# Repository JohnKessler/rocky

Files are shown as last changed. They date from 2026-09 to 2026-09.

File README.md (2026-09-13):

# Rocky



A compact desk companion. A round face that shows what it is thinking, a camera
that watches the room, a head on two motors that turns to look at you, and a
voice with opinions.

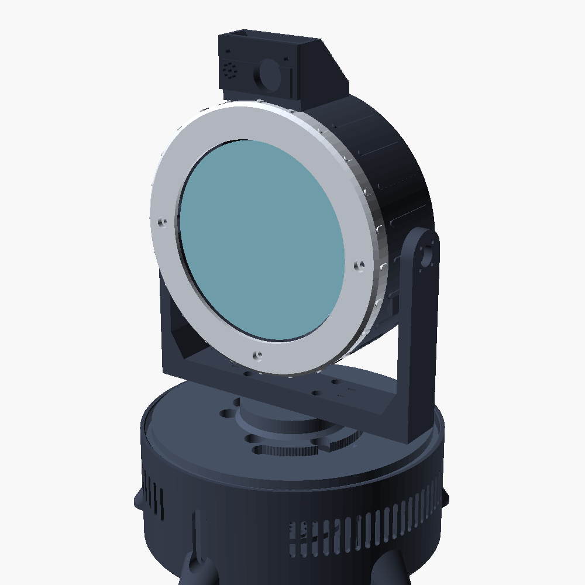
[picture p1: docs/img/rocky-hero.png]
Rocky


Rocky is an alien engineer who lives on your desk. It is blind in the way its
own kind are blind, it thinks in chords rather than words, and it finds most
things about humans genuinely puzzling. Ask it something and it will turn to
face you, think about it visibly, and answer in a sentence or two — usually
after a chord, because a chord is its first language and English is a
translation.

**188 × 184 × 273 mm — about 0.33 cubic feet.**

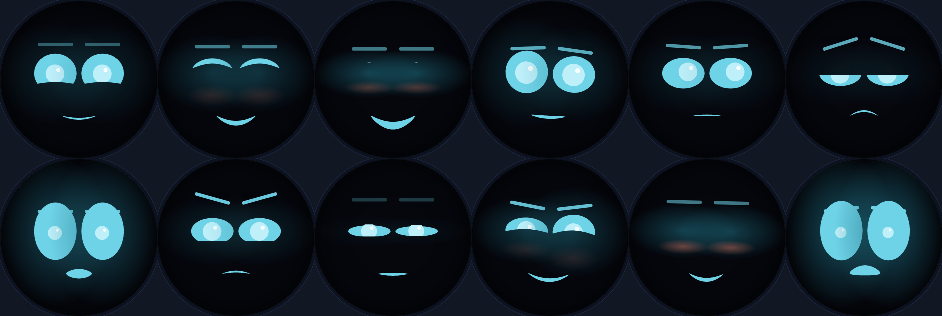
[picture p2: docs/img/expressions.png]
Rocky's expressions


---

## What it does

- **Watches.** A wide camera finds faces and the head turns to hold you near
  the centre of frame. When nobody is there it looks around now and then, the
  way something alive does.
- **Listens.** Wake word, then speech recognition. Or leave the mic open if
  you work alone.
- **Talks.** A voice pushed away from human, introduced by a musical motif
  chosen to match the expression.
- **Reacts.** Nineteen expressions and twelve gestures, driven by what Rocky
  actually means rather than sprinkled on afterwards. It nods while still
  looking at you.
- **Remembers.** Short facts it chose to keep, in a SQLite file you can open,
  read and delete.
- **Is tunable.** A dashboard for watching everything it does and adjusting
  how it behaves, live.

---

## Try it before you build it

Every hardware backend has a simulated twin, so the whole robot runs on a
laptop with nothing attached. The simulator is closed-loop: there is a subject
at a bearing in a synthetic room, turning the head moves it across the frame,
and face tracking genuinely converges.

```bash
git clone https://github.com/JohnKessler/rocky && cd rocky
python3 -m venv .venv && . .venv/bin/activate
pip install -e .

export ANTHROPIC_API_KEY=sk-ant-...     # optional; without it Rocky moves and
                                        # chirps but does not converse
rocky --sim run
```

Open **http://localhost:8080**. You get Rocky's real face — the browser renders
from the same parameter vector the display does — a simulated camera view with
detections, and every control the robot has.

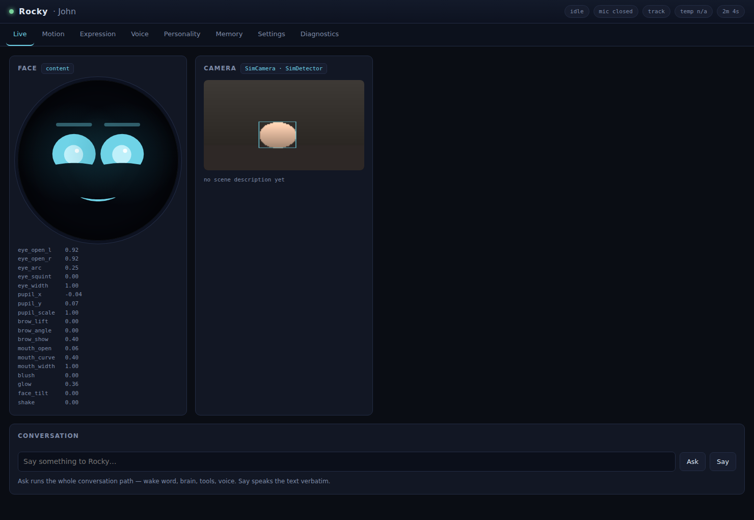
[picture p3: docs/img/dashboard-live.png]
Dashboard


Type into the conversation box. That text enters the pipeline at exactly the
point a real transcript would, so it exercises the whole path rather than a
shortcut around it.

---

## Building one

| | |
|---|---|
| **[Bill of materials](docs/BOM.md)** | Every part, what the specification actually needs to be, and what is worth spending money on. £330–£420. |
| **[Printing](docs/PRINTING.md)** | Eleven parts, ~780 g, two days of printer time. Settings and orientation per part. |
| **[Wiring](docs/WIRING.md)** | Pin by pin, plus the `config.txt` lines that make the Pi see the hardware. |
| **[Assembly](docs/ASSEMBLY.md)** | Four hours, in an order that works. |
| **[Software](docs/SOFTWARE.md)** | Install, calibrate, tune, and what every setting does. |
| **[Architecture](docs/ARCHITECTURE.md)** | How the code fits together, and why. |

Short version: Raspberry Pi 5 in the head behind a 4″ round display, Camera
Module 3 Wide in a sensor brow above the face, pan and tilt on a PCA9685,
I²S amplifier driving a down-firing speaker in the base, one 12 V input.

The CAD is parametric. Every dimension lives in one file, and the build script
re-renders all ten parts and checks each mesh is watertight, manifold and in
one piece before you waste filament on it.

```bash
cd hardware/cad && ./build_all.sh
```

---

## Repository

```
docs/            build guides and architecture notes
  bench-guide.html  the assembly, one stage at a time, for a phone at the bench
hardware/
  cad/           OpenSCAD source - rocky_params.scad holds every dimension
  stl/           exported, validated meshes
  wiring/        the wiring as data; generates the diagrams and the tables
  img/           assembly renders and wiring diagrams
  update_docs.py folds both into the guides
  README.md      how the graphics are generated
software/rocky/
  core/          event bus and service lifecycle
  face/          expressions, geometry, renderers
  motion/        kinematics, servos, gestures, tracking
  vision/        camera, detection, the simulated room
  audio/         wake word, speech, synthesis, chirps
  brain/         persona, memory, tools, conversation loop
  web/           dashboard API and front end
tests/           252 tests, all running against the simulated backends
scripts/         installer
systemd/         service unit
```

---

## How it is put together

Six services that never call each other. They publish events and subscribe to
topics, and one module knows they all exist. The consequences are worth the
indirection: a gesture the brain asked for and a gesture you triggered from the
dashboard take exactly the same path, and you can run Rocky without a camera by
editing one file.

Everything that touches hardware ships a real backend and a simulated one and
picks between them at runtime, which is why the test suite can boot the entire
robot.

Three decisions that shaped the rest:

- **The tilt axis runs through the head's centre of mass**, with a trim-weight
  post to get it there. Balanced, the tilt servo fights only inertia — which is
  what lets it be a micro servo, which is what lets the Pi fit beside it, which
  is what keeps the head small enough to balance.
- **The servos de-energise when the head has been still for a moment.** A
  digital servo holding position against its own gear lash hums continuously.
  This one setting is most of the difference between a robot you leave on your
  desk and one you put in a cupboard.
- **The camera lives in a brow above the face, not behind it.** A 24 mm camera
  board will not fit above a 110 mm display inside any sensible head diameter —
  the geometry simply does not close. So Rocky has an eye stalk, which suits it.

---

## A note on Rocky

The character is an affectionate original take in the manner of the Eridian
engineer from Andy Weir's *Project Hail Mary* — an alien who is blind,
tireless, completely without guile, and whose first language is music. The
persona prompt in `software/rocky/brain/persona.py` is written from scratch
rather than quoting the book, and the chords are synthesised rather than
sampled. It is a homage, built for one desk. If you build your own, keep it
that way.

---

## Licence

MIT for the code and the CAD. See [LICENSE](LICENSE).

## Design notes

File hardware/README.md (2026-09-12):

# Regenerating the graphics

Every picture in the guides is generated from the same source as the thing it
depicts, so a figure cannot quietly go stale. Nothing here is hand-drawn and
nothing needs to be redrawn when a dimension changes.

```
rocky_params.scad ──► part .scad ──► .stl ──────────┐
                                                     ├─► assembly_guide.scad ──► .png + .legend
                      components.scad ──────────────┘

wiring_data.py ──► generate.py ──► wiring-*.svg
               └─────────────────► tables.md

                                   update_docs.py ──► docs/ASSEMBLY.md, docs/WIRING.md
```

## The whole chain

```bash
cd hardware/cad && ./build_all.sh        # 11 parts, each mesh validated
./render_figures.sh                      # 9 figures + their legends
cd .. && python3 wiring/generate.py      # 3 diagrams + the tables
python3 update_docs.py                   # fold both into the markdown
```

`build_all.sh` and `render_figures.sh` need OpenSCAD on `PATH`. `generate.py`
and `update_docs.py` are plain Python with no dependencies.

## Assembly figures

`cad/assembly_guide.scad` imports the exported STLs and the stand-in components
in `cad/components.scad`, then draws one figure per assembly stage. Which
figures exist, and the camera for each, is the `FIGURES` list at the top of
`cad/render_figures.sh`:

```
"stage4|1800 1250|0,0,70,54,0,205,470|1.0|80"
 view   size       camera                explode  label distance
```

Callouts are numbered discs with leaders, not text in the model — text at model
scale is unreadable at some camera distances and illegible at others. Each
`callout()` echoes its own caption, `render_figures.sh` captures those into
`img/assembly-<view>.legend`, and `update_docs.py` writes them under the image
as a numbered key. The numbers in the picture and the words in the document
therefore come from one place and cannot disagree.

## Wiring diagrams

`wiring/wiring_data.py` is the single description of Rocky's electrics: the
devices, which half of the robot each lives in, every link between them, and
the conductors that cross the pan joint. `generate.py` renders it three ways
(power, GPIO header, interconnect) as hand-built SVG, and writes the same data
out as markdown tables.

`validate()` runs before anything is drawn and refuses to generate on a
contradiction. It checks that every link's endpoints exist, that no GPIO pin is
claimed twice, and — the rule that earns its keep — that any link joining a
device in the head to a device in the base is marked as crossing the pan joint.
That last check caught a real design error: the amplifier sat in the base while
the Pi sat in the head, which quietly put a 3 MHz I²S clock across a harness
that flexes every time Rocky turns. The amplifier moved into the head.

## Markers

`update_docs.py` fills the region between marker pairs in `docs/*.md`:

```markdown
<!-- figure:stage4 -->
<!-- /figure -->

<!-- wiring:power -->
<!-- /wiring -->

<!-- tables:harness -->
<!-- /tables -->
```

Anything between a pair is overwritten. Edit the source, re-run the chain, and
never edit inside the markers by hand.

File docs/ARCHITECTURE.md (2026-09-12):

# Architecture

How the code fits together, and the reasoning behind the parts that are not
obvious.

## The shape of it

Six services that never call each other. They publish events onto an in-process
bus and subscribe to topics; one module, `rocky/app.py`, knows they all exist.

```mermaid
graph LR
    subgraph inputs [ ]
        AUDIO[audio<br/>wake · speech · voice]
        VISION[vision<br/>camera · detection]
    end
    BUS{{event bus}}
    BRAIN[brain<br/>persona · memory · tools]
    subgraph outputs [ ]
        FACE[face<br/>expressions · animation]
        MOTION[motion<br/>servos · gestures · tracking]
    end
    WEB[web<br/>dashboard]

    AUDIO <--> BUS
    VISION --> BUS
    BUS <--> BRAIN
    BUS --> FACE
    BUS --> MOTION
    BUS <--> WEB
    MOTION -. pose .-> VISION
```

The indirection earns its keep three ways:

- A gesture the brain asked for and a gesture you clicked in the dashboard take
  **exactly the same path**, so the dashboard is a real test of the robot rather
  than a parallel implementation of it.
- Running without a camera, or with the face on another machine, is an edit to
  one file.
- Every service can be tested by feeding it events.

The dotted line from motion back to vision is the simulator closing its own
loop; on real hardware the world does that.

## Simulation is not a stub

Every hardware-facing module ships a real backend and a simulated one and picks
at runtime:

| | Real | Simulated |
|---|---|---|
| Servos | PCA9685 over I²C | records channel state |
| Camera | picamera2 | renders a room with someone in it |
| Detection | MediaPipe / Haar cascade | reads the simulator's ground truth |
| Display | pygame on the panel | records the parameter vector |
| Audio | PortAudio | room tone in, buffer out, **in real time** |
| Speech in | faster-whisper | a queue you can push text onto |
| Speech out | Piper / espeak-ng | silence of the right duration |

Two of these are worth dwelling on, because the easy version of each would have
made the simulator lie.

**The camera is closed-loop.** The subject sits at a real bearing in a synthetic
room and drifts slowly; where it lands in frame depends on where the head is
pointing, fed back from the motion service. Turn the head and the subject moves
across the frame as it would through a real lens. Face tracking therefore
genuinely converges in simulation, and a change that makes Rocky overshoot or
hunt shows up in a test instead of on your desk. If the subject falls outside
the lens's field of view it is simply not in the picture, which is what makes
the idle scanning behaviour mean anything.

**Simulated playback occupies real time.** Returning instantly would be faster,
but everything downstream of "Rocky is speaking" keys off how long it lasts —
the mouth animation, the gesture timing, and the gate that stops Rocky
transcribing its own voice. None of it would ever be exercised. The suite turns
this off via `hardware.sim_realtime_audio`; the one test that is actually about
speaking timing turns it back on for itself.

## The face is a parameter vector

An expression is a point in an eighteen-dimensional space and everything between
two expressions is a blend, so the face travels rather than cutting. Three
layers stack each frame:

1. the expression, cross-fading toward whatever was last requested
2. involuntary life — blinks, saccades, a slow swell in the glow
3. gaze, so the pupils reach you before the head finishes turning

Layer 2 is what stops the face reading as a picture. A face that holds perfectly
still is unsettling in a way that is hard to name and impossible to miss.

Two renderers consume the same vector: pygame on the panel, and SVG in the
browser. Because both read the same numbers, the dashboard shows Rocky's actual
face. The geometry maths is duplicated — `layout()` in `face/renderer.py` and
`layout()` in `static/js/face.js` — which is a real cost, paid to keep the
websocket carrying eighteen floats instead of a video stream.

Rendering the dashboard in a browser found two bugs in geometry both renderers
shared: the eyelid mask covered the whole lower half of the eye regardless of
the arc parameter, erasing the pupils of every smiling face; and the mouth's
curve sign was inverted, so every smile drew as a frown.

## Motion has exactly one writer

Everything that wants to move the head publishes an event; the motion loop is
the only thing that writes to a servo. That single-writer rule is what stops
tracking, gestures and dashboard jogging fighting each other.

Each tick the commanded angle is:

```
base (tracking, or a look_at, or idle drift)  +  gesture overlay
```

Offsets, not absolute positions, which is why Rocky can nod while still looking
at you.

### The motion profile

`MotionProfile` computes the fastest speed from which it could still brake to a
standstill exactly on target, and never exceeds it. The result is a trapezoid —
ramp up, cruise, ramp down — which is the movement people read as deliberate
rather than servo-ish.

It uses the **discrete-time** braking solution, not `v = sqrt(2·a·d)`. The
continuous form permits a speed that overshoots by up to one integration step,
and overshoot on a head this size reads as a twitch. Solving
`v² + 2·a·dt·v − 2·a·d ≤ 0` accounts for the step. The tests assert zero
overshoot and bounded acceleration *of the commanded position*, which is the
physical claim — the servo is driven by position, not by the profile's internal
velocity variable.

### Tracking

Proportional, with a deadband, and deliberately not a full PID. An integral term
on a servo with backlash walks the head slowly off target; a derivative term on
a jittery detector makes it twitch. Proportional plus a deadband plus the
profile's own acceleration limit produces the unhurried turn that reads as
attention rather than machinery.

### Torque

The servos de-energise after `motion.idle_torque_off_s` at rest. A digital servo
holding position against its own gear lash hums continuously, and this one
setting is most of the difference between a robot you leave out and one you put
away.

## The brain

One manual tool-use loop, not the SDK's tool runner, because each tool call has
to become a bus event the instant it happens — Rocky's face should change while
it is still deciding what to say, and the runner does not expose that seam.

Ten tools, all of which act by publishing events. One is different: `see`
returns the actual camera frame as image content blocks rather than a
description, so the model looks at the picture.

The system prompt and the tool list are byte-identical every turn and are
cached. Situational context — what Rocky can see, what it remembers — goes into
the *user* turn rather than the system prompt, specifically so the cached prefix
survives. A clock in the system prompt would throw the cache away on every
single request.

Everything that costs an API call lives in `brain/`. Vision publishes frames and
detections and says when the room changed; it never calls the model. One place
spends money, one place to look when the bill is wrong.

## Memory

A table of short facts Rocky chose to keep and a rolling transcript, in a SQLite
file you can open with any tool. That is deliberate for something that lives on
your desk and remembers things about you: you should be able to see exactly what
it has and delete any of it, from the dashboard or with `sqlite3`.

Pruning is by uses then age, so something Rocky keeps coming back to survives
even when it is old.

## Configuration

One pydantic tree, live-patchable by dotted path, with bounds on every field.
The dashboard's settings tab is generated from the schema — type, bounds,
choices and help text — so adding a setting in Python gives it the right control
in the browser with the right limits and no edit to the front end.

The bounds are enforced wherever a value enters, which is why a slider cannot
drive a servo past its limits. Behind that, `motion/kinematics.py` clamps
whatever the config says to the envelope the printed parts allow, and behind
*that* the printed stop post and stop pins are physical.

## Where the CAD and the code meet

`hardware/cad/rocky_params.scad` and `software/rocky/` are kept in step by hand
at exactly three points, all of them documented in both places:

- `MECHANICAL_LIMITS` in `motion/kinematics.py` mirrors `pan_range` and
  `tilt_range`
- `vision.h_fov_deg` / `v_fov_deg` must match the fitted lens
- `face.width` / `face.height` must match the panel

Everything else about the chassis is invisible to the software.

## Reading order

If you are picking this up cold:

1. `core/events.py` — the vocabulary everything speaks
2. `core/bus.py` — how it moves
3. `motion/kinematics.py` — pure arithmetic, no hardware, fully tested
4. `face/expressions.py` — the face as numbers
5. `app.py` — the wiring, in one screen
6. `brain/agent.py` — the conversation loop

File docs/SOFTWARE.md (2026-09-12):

# Software

Install, calibrate, and tune.

## Install on the Pi

```bash
git clone https://github.com/JohnKessler/rocky /tmp/rocky
sudo /tmp/rocky/scripts/install.sh
```

That installs system packages, enables I²C, creates a `rocky` user with the
right groups, builds a virtualenv at `/opt/rocky/.venv`, and installs a systemd
unit. It is safe to re-run — it upgrades in place and leaves `config.toml`
alone.

Then put your API key where the service can find it:

```bash
sudo nano /etc/rocky/rocky.env     # ANTHROPIC_API_KEY=sk-ant-...
sudo systemctl start rocky
journalctl -u rocky -f
```

Without a key Rocky still watches, tracks, moves and chirps. It just does not
converse.

### Speech engines

The installer tries to install `faster-whisper`, `piper` and `openwakeword`.
They are large and occasionally fight a particular Pi image, so failure is
non-fatal: Rocky falls back to `espeak-ng` for speech out and to a
speech-triggered wake for speech in, and says so in the log.

Piper needs a voice model on disk. Download one and drop it in
`/opt/rocky/var/voices/`:

```bash
cd /opt/rocky/var/voices
wget https://huggingface.co/rhasspy/piper-voices/resolve/main/en/en_GB/alan/medium/en_GB-alan-medium.onnx
wget https://huggingface.co/rhasspy/piper-voices/resolve/main/en/en_GB/alan/medium/en_GB-alan-medium.onnx.json
```

Then set `audio.tts.voice = "en_GB-alan-medium"`.

For the wake word, openWakeWord ships several pretrained models but not
"hey rocky". Either train one (their docs cover it), pick an existing model and
set `audio.wake.model`, or set `audio.wake.backend = "energy"` and let any
sustained speech wake Rocky. Energy wake is pleasant if you work alone and
useless in a room with a television.

## Commands

```bash
rocky run                  # the normal one
rocky run --no-web         # without the dashboard
rocky --sim run            # everything simulated, works anywhere
rocky check                # probe the hardware and report what is real
rocky calibrate pan        # interactive centring, writes the trim back
rocky calibrate tilt
rocky ask "what can you see"
rocky say "Good, good, good."
rocky config               # print the effective configuration
```

`rocky check` is the one to run first on a fresh build. It reports every backend
as `ok` (real hardware) or `sim` (fell back), which turns "why is nothing
happening" into a list.

## Configuration

Precedence, lowest to highest:

```
defaults in config.py  →  config.toml  →  ROCKY_* environment  →  dashboard edits
```

Dashboard edits apply immediately and are lost on restart unless you press
**Save**, which writes them back to `config.toml`. That is deliberate: you can
experiment freely and a bad idea disappears when you restart.

Environment overrides use a double underscore between levels:

```bash
ROCKY_MOTION__PAN__MAX_SPEED_DPS=90
ROCKY_BRAIN__EFFORT=medium
ROCKY_LOG_LEVEL=DEBUG
```

Every setting is bounded, and the bounds are enforced wherever the value enters
— including from the dashboard, which is why a slider cannot drive a servo past
its limits.

## Calibration

### Servo centres

```bash
rocky calibrate pan
```

`a`/`d` nudge by a degree, `A`/`D` by five, `0` commands zero, `s` saves and
quits. It writes `motion.<axis>.centre_trim_deg`.

Do this rather than trying to get the horn splines mechanically perfect. A
standard servo spline is 1.5° per tooth, so mechanical alignment can only ever
get you within three quarters of a degree; the trim gets you exact.

### Camera field of view

`vision.h_fov_deg` and `v_fov_deg` must match your lens. They are what convert
"the face is 30% right of centre" into "turn 15 degrees", so a wrong value makes
Rocky consistently under- or over-shoot when it turns to look at you.

- Camera Module 3 **Wide**: 102 × 67 (the default)
- Camera Module 3 standard: 66 × 41

To check empirically: put your face at the edge of frame, let Rocky track it,
and watch whether the head lands short or long. Short means the FOV is set too
narrow.

### Tracking

If Rocky overshoots and corrects back, lower `motion.tracking.gain` — try 0.4.
If it creeps continuously while you sit still, raise
`motion.tracking.deadband`. If it feels twitchy, raise `damping`.

The **Motion** tab shows the head's position and its target on one map, which
makes overshoot and hunting obvious.

## Tuning Rocky's personality

The **Personality** tab has seven dials. They are not decoration — each one is
quoted into the prompt and read by the face and motion services, so a change
takes effect within a second or two.

| Dial | What it changes |
|---|---|
| `curiosity` | How often Rocky asks about things, and how much it looks around when idle |
| `chattiness` | Whether Rocky speaks unprompted, including whether it greets you |
| `playfulness` | Teasing, jokes, sillier chords |
| `warmth` | How openly it says it likes you |
| `formality` | Sentence register. Low is the default; Rocky's speech is plain by design |
| `energy` | Gesture amplitude, blink rate, speech pace |
| `focus` | How long it stays on a subject, and how much its eyes wander |

Rocky can turn these itself. Say "be quieter" and it will reach for its
`adjust_self` tool, which is the same code path as the slider.

To change the character more deeply, edit `software/rocky/brain/persona.py`.
It is assembled rather than written flat so you can read exactly what each dial
contributed.

## Cost

Rocky makes one API request per conversational turn, plus one small request
whenever it describes the scene.

Levers, in the order worth reaching for:

1. `vision.scene_interval_s` — how often Rocky looks at the room. The default
   of 45 s with `scene_on_change_only` is already conservative; raise it or set
   `brain.scene_in_context = false` to stop entirely.
2. `brain.effort` — `low` by default, because a spoken companion answers in a
   sentence or two and the gap between you stopping and Rocky starting matters
   more than depth. Raise it if you start asking harder questions.
3. `brain.history_turns` — how much conversation is resent each turn.
4. `brain.max_tokens` — a hard ceiling on the reply.

The system prompt and tool list are identical every turn and are cached, so most
of the per-turn input cost disappears after the first request. The **Personality**
tab shows requests, tokens and cache hits; if `cached` stays at zero across
several turns, something is varying in the prefix.

## Running it your own way

`rocky run` starts everything. If you want a subset, `RockyApp` takes a config
and starts whichever services you leave enabled:

```python
from rocky.app import RockyApp
from rocky.config import Config

cfg = Config.load()
cfg.vision.enabled = False      # no camera
cfg.motion.enabled = False      # no servos

app = RockyApp(cfg)
await app.start()
await app.say("Good, good, good.")
```

The web app can own the robot's lifecycle if you would rather embed it:

```python
from rocky.web.app import create_app
api = create_app(RockyApp(cfg), manage_lifecycle=True)
```

## Tests

```bash
pip install -e ".[dev]"
pytest
```

252 tests, about forty seconds, all against the simulated backends — so they
pass on a laptop, in CI, and on the robot. They are worth reading if you plan to
change anything: several assert on behaviour that is easy to break silently,
like the motion profile never overshooting, the eyelid never covering the pupil,
and the microphone being shut while Rocky talks.

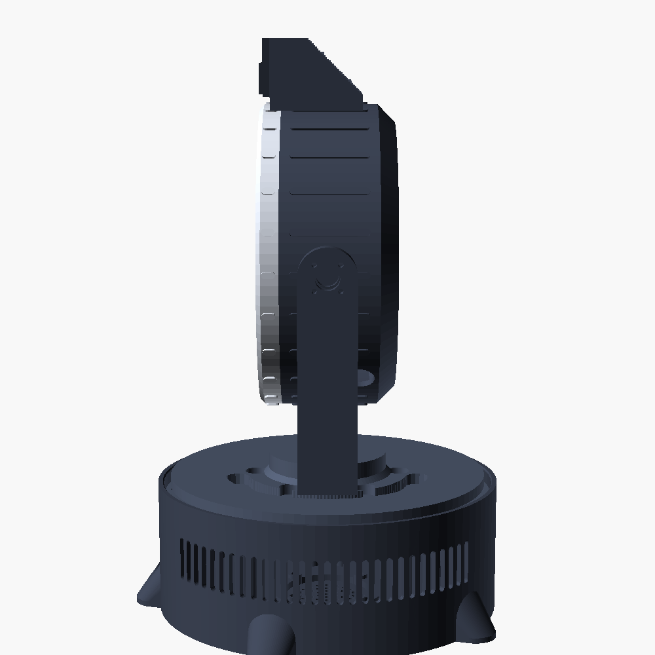
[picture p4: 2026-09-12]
hardware/img/rocky_side.png

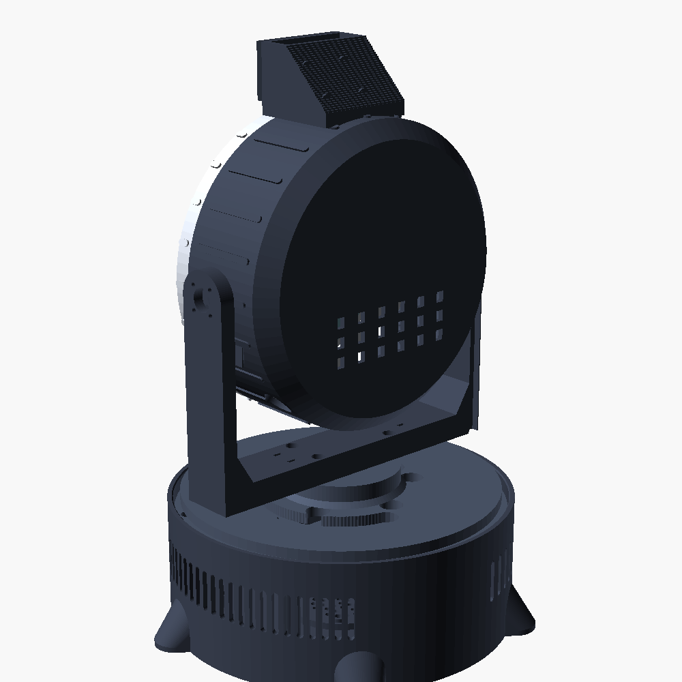
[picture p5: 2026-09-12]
hardware/img/rocky_three_quarter.png

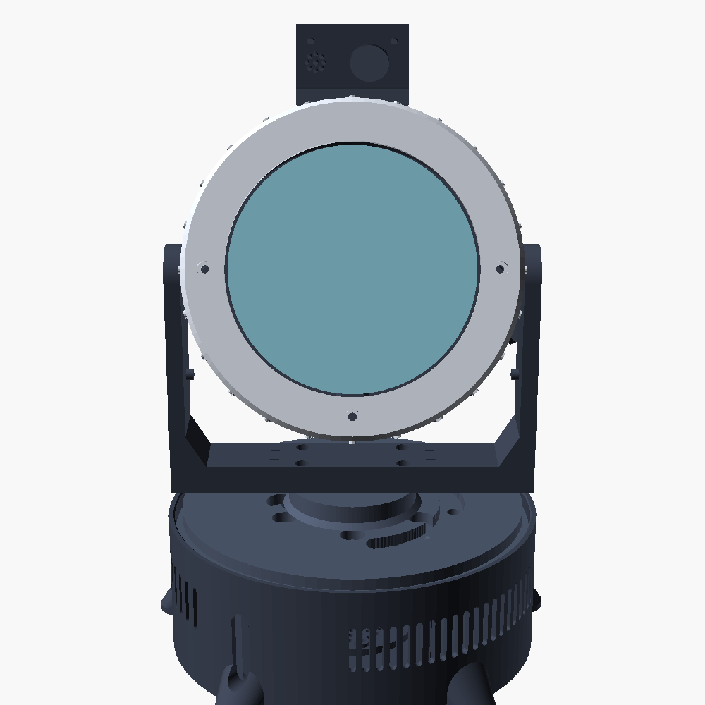
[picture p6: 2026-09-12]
hardware/img/rocky_tilted.png

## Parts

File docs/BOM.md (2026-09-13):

# Bill of materials

Everything needed to build one Rocky. Roughly **£330–£420 / $420–$530**
depending on which display and speech engine you choose and what you already
have in a drawer.

> **Check part numbers before you order.** SKUs and prices move, and vendors
> revise boards without renaming them. The **Specification** column is the part
> that actually matters — anything meeting it will work, and the code and the
> printed parts are parameterised so substitutions are a number change rather
> than a redesign. Where a dimension feeds the CAD, the parameter name is given
> so you know what to edit.
>
> Vendor SKUs were last checked on **12 September 2026**. Three were wrong at
> that point and are corrected below: the Qwiic cable had been retired, the
> speaker had been relabelled and had lost its colour-coded leads, and the
> microphone that was suggested does not fit the printed mount. The brow has
> since been recut around the flat stick instead (item 5.3), so the mount is
> now the part that changed rather than the microphone.

Vendor shorthand: **SF** SparkFun · **AF** Adafruit · **RPi** Raspberry Pi (or
any approved reseller) · **WS** Waveshare · **\*** generic, buy anywhere.

---

## 1. Brain

| # | Part | Specification | Where | ~Cost |
|---|---|---|---|---|
| 1.1 | Raspberry Pi 5, 8 GB | 8 GB matters: the face renderer, the detector and local speech all want headroom. 4 GB works if you use cloud speech. | RPi | £75 |
| 1.2 | Active Cooler for Pi 5 | The official one. Rocky's head is a closed box and the Pi will throttle without it. Its height sets `pi_stack_h`. | RPi | £5 |
| 1.3 | microSD card, 64 GB, A2 | A2 rating, not just "class 10". Cheap cards make boot and model loading miserable. | \* | £10 |
| 1.4 | *(optional)* NVMe HAT + 256 GB SSD | Only if you want local Whisper models to load quickly. Adds height in the head — check clearance first. | RPi | £45 |

## 2. Face

| # | Part | Specification | Where | ~Cost |
|---|---|---|---|---|
| 2.1 | **Option A —** 4″ round DSI display, 720×720 | Round IPS, MIPI-DSI, 60 Hz. This is the one the faceplate is drawn for. Measure the glass diameter and the carrier PCB and set `disp_glass_d`, `disp_pcb_w`, `disp_hole_dx/dy` before printing. | WS | £45 |
| 2.2 | **Option B —** Raspberry Pi Touch Display 2 | 5″, 720×1280, officially supported so the driver situation is boring. Not round: reprint `faceplate.scad` with `circular_mask=false` and a rectangular window, or accept a letterboxed face. Pick this if Option A's overlay fights your kernel. | RPi | £55 |
| 2.3 | DSI FPC cable, 22-pin 0.5 mm → 15-pin 1 mm, 200 mm | **Pi 5 only.** The Pi 5's connectors are the smaller 22-pin format; a standard 15-pin ribbon will not fit. Must be the *display* cable — the camera one is not interchangeable. | AF 5821 / WS | £5 |

## 3. Eyes

| # | Part | Specification | Where | ~Cost |
|---|---|---|---|---|
| 3.1 | Raspberry Pi Camera Module 3 **Wide** | 12 MP IMX708, autofocus, 102° × 67° FOV. Vendors advertise this lens as **120°**, which is the *diagonal* figure; 102° × 67° is the same lens measured horizontally and vertically, and horizontal is what the tracking maths wants. The wide version is the right call: the standard lens's 66° is too narrow to find you when Rocky is looking somewhere else. FOV feeds `vision.h_fov_deg` / `v_fov_deg` — get these wrong and Rocky consistently mis-aims when it turns to look at you. | RPi / AF 5658 | £30 |
| 3.2 | Camera FPC cable, 22-pin → 15-pin, 200 mm | Again Pi 5 specific, and again *not* the display cable. | AF 5818 / WS | £5 |

## 4. Motion

| # | Part | Specification | Where | ~Cost |
|---|---|---|---|---|
| 4.1 | Pan servo — standard size, metal gear, digital | 40.6 × 20 × 37 mm, ≥ 5 kg·cm at 6 V, 180°. A quiet digital servo is worth the extra: this one sits 30 cm from your ear. Hitec HS-5485HB or Savöx SH-0255MG are pleasant; MG996R works and is noticeably louder. Dimensions feed `sv_*`. | SF / \* | £18 |
| 4.2 | Tilt servo — micro, metal gear | 23 × 12.2 × 22.5 mm, ≥ 2 kg·cm. MG90S or Hitec HS-5065MG. **A standard servo will not fit** beside the Pi in the head — the head is sized around a micro here. Dimensions feed `msv_*`. | SF / \* | £8 |
| 4.3 | PCA9685 16-channel PWM/servo driver | I²C, 12-bit, external servo supply via screw terminal. Only two channels are used; the rest are there when you want to add something. | AF 815 / SF | £12 |
| 4.4 | Qwiic SHIM for Raspberry Pi | Slips over the GPIO header and gives you I²C on a connector **without covering the header**, which is what leaves GPIO 18/19/21 free for the amplifier. | SF DEV-15794 | £2 |
| 4.5 | Qwiic cable, 4-pin → female jumpers | Connects the SHIM to the PCA9685's I²C header. Wires are red/black/blue/yellow, matching the table in [WIRING.md](WIRING.md). **CAB-14988 (150 mm) is retired** — the current equivalent is the *Flexible Qwiic Cable – Female Jumper (4-pin)*, CAB-17261. Check the length suits; anything from 100–200 mm is fine. | SF CAB-17261 | £2 |
| 4.6 | Chrome steel balls, 6 mm × 30 | The slew ring. Buy 30 for 24 positions — you will lose some. 6 mm airsoft BBs work but wear faster and are noisier. | \* | £4 |
| 4.7 | 623ZZ bearing (3 × 10 × 4 mm) | The tilt idler pivot. | \* | £1 |
| 4.8 | 470 µF 10 V electrolytic capacitor | Across the servo rail at the PCA9685. Not optional — servo inrush browns out the I²C bus without it, and the symptom is Rocky freezing mid-move for no visible reason. | \* | £1 |

## 5. Voice

| # | Part | Specification | Where | ~Cost |
|---|---|---|---|---|
| 5.1 | MAX98357A I²S class-D amplifier | 3 W into 4 Ω, I²S in. The Pi 5 has no headphone jack, so this is required rather than optional. Mounts in the **head**, beside the Pi — that way the pan joint carries two analogue speaker conductors instead of five digital ones. | AF 3006 / SF | £6 |
| 5.2 | Speaker, 40 mm, 4 Ω, 3–5 W | Mounts in the **base** floor, firing down into the gap the legs hold open. Frame diameter feeds `spk_d`; the body is about 20 mm deep. Adafruit now lists 3968 as **5 W** where distributors still print 3 W — same part, and the extra headroom is harmless since the amplifier only delivers 3.2 W. The January 2024 revision has a concave cone and **no longer ships red/black leads**, so identify polarity yourself rather than by colour. | AF 3968 / \* | £4 |
| 5.3 | USB microphone, **flat stick, 22.2 × 18.3 × 7.0 mm** | The brow is cut for this exact shape: Adafruit's Mini USB Microphone (3367), and the physically identical part sold by Pi Hut, SunFounder, Cytron, Seeed and PiShop. It needs no bracket and no screws — stood on edge it drops into a slot moulded into the brow. Dimensions feed `mic_body_x/y/z`. **A cylindrical gooseneck or barrel mic will not fit**: the slot beside the camera is 13.6 mm wide and a 14 mm body overhangs the brow's wall. Anything else means editing `mic_body_*` and reprinting `head_back`, so measure before you buy. A small far-field array (ReSpeaker USB Mic Array, or similar) is a large improvement over a single capsule if Rocky sits more than a metre away, and is a separate mounting problem again. | \* | £8–£55 |
| 5.4 | USB-A right-angle adapter or short extension | The Pi's ports face sideways inside the head; a straight plug fouls the shell. | \* | £3 |

## 6. Power

Rocky takes **one 12 V input** and makes its own rails. Two wall warts on a desk
is an unforced ugliness, and feeding the Pi 5 from a bare 5 V supply makes it
throttle USB current and complain.

| # | Part | Specification | Where | ~Cost |
|---|---|---|---|---|
| 6.1 | 12 V 5 A PSU, 2.1 mm centre-positive barrel | 60 W. 3 A is enough in practice; 5 A means the servos never sag the rail. | \* | £12 |
| 6.2 | Step-down regulator, 5.1 V ≥ 5 A | For the Pi. Pololu D36V50F5 or equivalent. **5.1 V, not 5.0** — cable drop at 4 A is real and the Pi 5 is fussy about it. Hole spacing feeds `buck_hole_dx`. | Pololu / \* | £18 |
| 6.3 | Step-down regulator, 6 V ≥ 3 A | For the servo rail. 6 V gets meaningfully more torque and speed than 5 V out of the same servos. | Pololu / \* | £10 |
| 6.4 | USB-C breakout or a sacrificial USB-C cable | To feed the Pi's USB-C input from the 5.1 V rail. A cut-down cable is fine; solder to the 5 V and GND pairs. | \* | £4 |
| 6.5 | Panel-mount 2.1 mm DC jack | Base wall, cutout is `barrel_d`. | \* | £2 |
| 6.6 | 12 mm panel-mount latching switch | Base wall, cutout is `switch_d`. | \* | £3 |
| 6.7 | Inline fuse holder + 3 A fuse | On the 12 V input. A shorted servo lead behind a 5 A supply is a fire, not a fault. | \* | £2 |

## 7. Fasteners

Buy an M2/M2.5/M3 assortment and a heat-set insert kit; it is cheaper than
buying each length and you will use the rest.

| # | Part | Quantity | Notes |
|---|---|---|---|
| 7.1 | M3 heat-set inserts, 5.0 mm OD × 4.0 mm | 20 | Stage 1 uses 15. Pilot bores are `m3_insert_d`. |
| 7.2 | M2.5 heat-set inserts, 3.5 mm OD × 4.0 mm | 30 | Display, Pi, pan servo, and the pads in the base. Stage 1 uses 24; the rest are for the one you melt in crooked. Not the brow window — that takes self-tappers. |
| 7.3 | M2 heat-set inserts, 4.0 mm long | 10 | Camera posts and the amplifier pads, 6 in Stage 1. The bores in the CAD are `m2_insert_d` = 3.2 mm, so buy inserts specified for a 3.2 mm melt-in hole rather than by their OD. |
| 7.4 | M3 socket cap screws, 8 / 12 / 16 / 20 mm | 10 each | |
| 7.5 | M2.5 screws, 6 / 10 / 16 mm | 10 each | |
| 7.6 | M2 and M2.5 self-tapping screws, 8 mm | 10 each | Straight into printed bosses: M2 for the tilt servo's ears, M2.5 for `pod_window`. |
| 7.7 | M3 × 20 socket cap screw | 1 | The tilt pivot — it passes through the 623ZZ bearing. |
| 7.8 | M8 washers | 10–20 | Head trim weights. How many is a balance question, not a fixed number. |
| 7.9 | Self-adhesive felt pads, 12 mm | 5 | Under the legs. |
| 7.10 | Silicone wire, 20 AWG and 26 AWG | 2 m each | 20 AWG for power, 26 AWG for signals. Silicone, not PVC — the pan joint flexes this wire thousands of times. |
| 7.11 | Heat-shrink, JST-XH connectors, cable ties | assorted | |

## 8. Printing and consumables

| # | Item | Notes |
|---|---|---|
| 8.1 | PETG filament, ~600 g | Preferred. The parts hold heat-set inserts better than PLA and will not sag in a warm room or a car. |
| 8.2 | PLA, ~600 g | Fine, prints easier, but do not leave Rocky on a sunny windowsill. |
| 8.3 | TPU 95A, a few grams | The speaker gasket only. Skip it and use a smear of neutral-cure silicone instead. |
| 8.4 | PTFE or lithium grease | The slew ring. A little, on the balls. |

## 9. Tools

Soldering iron with a heat-set insert tip (a cheap conical tip works), side
cutters, hex drivers, a small screwdriver set, digital calipers, multimeter.
**Calipers are the one you should not skip** — three groups of numbers in
`rocky_params.scad` are marked MEASURE because vendors ship revisions, and
measuring them takes two minutes against an afternoon of reprinting.

---

## What matters and what does not

**Worth the money**

- *A quiet pan servo.* You will hear this one every time Rocky turns. It is the
  difference between a robot you keep on your desk and one you move to a shelf.
- *The wide camera lens.* A narrow lens means Rocky loses you constantly.
- *A decent microphone.* Speech recognition quality is dominated by the
  microphone, not the model. A far-field array is the single biggest upgrade
  available to this build.

**Do not bother**

- *An expensive display.* Rocky's face is flat colour on black; panel quality is
  invisible at this content. Buy on size and driver support.
- *Servos above about 8 kg·cm.* The head is light and balanced on its tilt axis.
  Extra torque buys noise and current draw, not capability.
- *NVMe*, unless you are running local Whisper and impatient.

**Sensible substitutions**

- **Pi 4 instead of Pi 5.** Works. Use the plain 15-pin camera and display
  cables (items 2.3 and 3.2 become unnecessary), and expect the face to run
  closer to 25 fps than 45. Set `face.fps` down to match.
- **Cloud speech instead of local.** Set `audio.stt.backend` and
  `audio.tts.backend` and skip the Whisper and Piper installs. Lower latency,
  better voices, but Rocky stops working when your internet does.
- **Any I²C servo driver.** Nothing depends on the PCA9685 specifically beyond
  `rocky/motion/servo.py`, which is about forty lines.

**Do not substitute**

- **The tilt servo for a standard-size one.** It will not fit. The head is
  dimensioned around a micro servo sitting beside the Pi, and that is what makes
  the head small enough to balance on its own tilt axis.

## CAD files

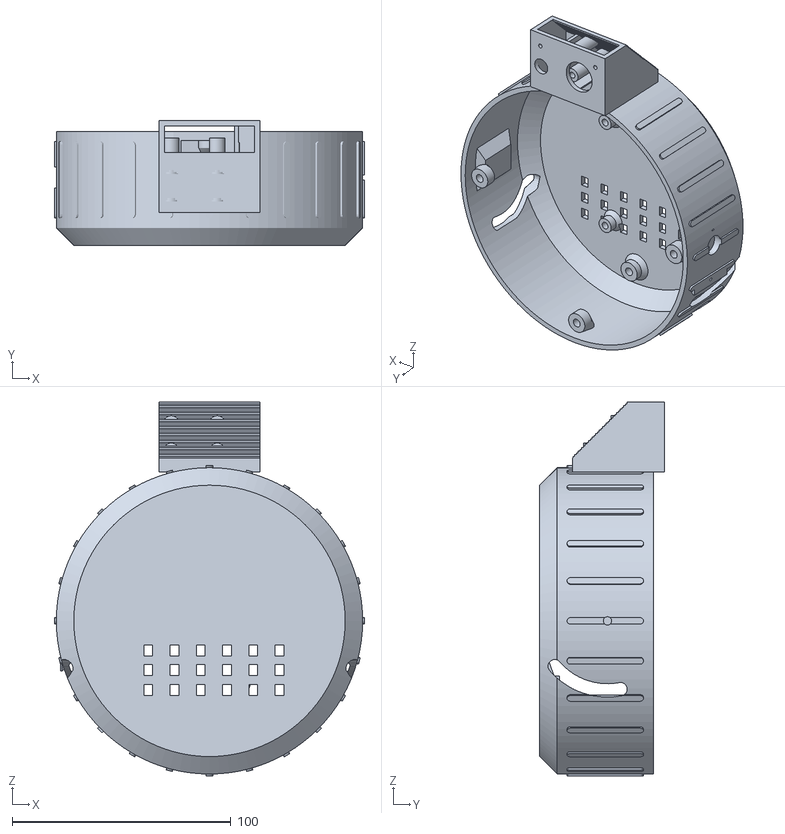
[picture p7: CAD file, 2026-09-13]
hardware/stl/head_back.stl
141.8 x 57.0 x 170.9

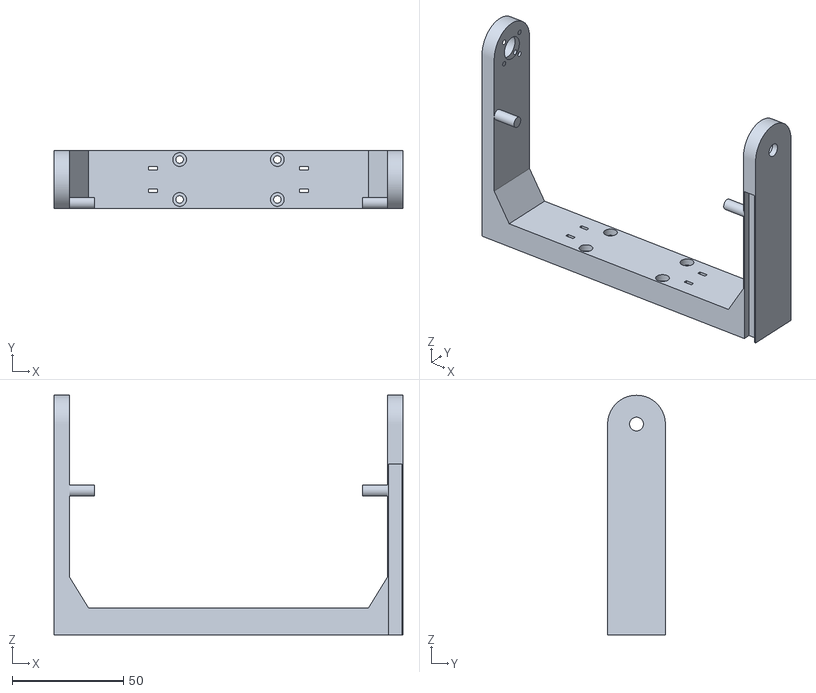
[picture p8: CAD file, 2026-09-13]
hardware/stl/yoke.stl
157.2 x 26.0 x 107.9

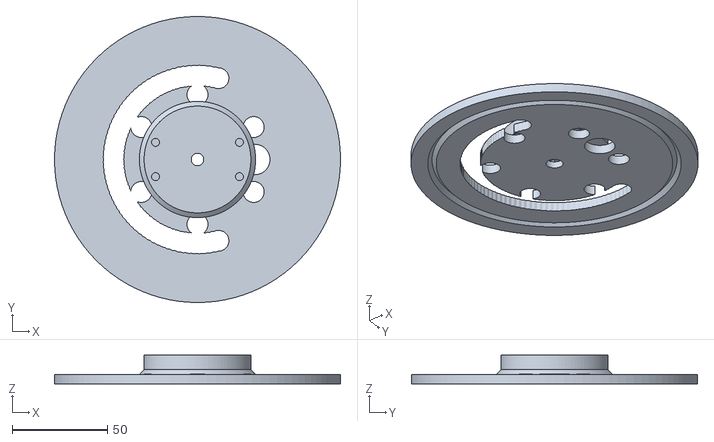
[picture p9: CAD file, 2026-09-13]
hardware/stl/turntable.stl
150.0 x 150.0 x 15.0

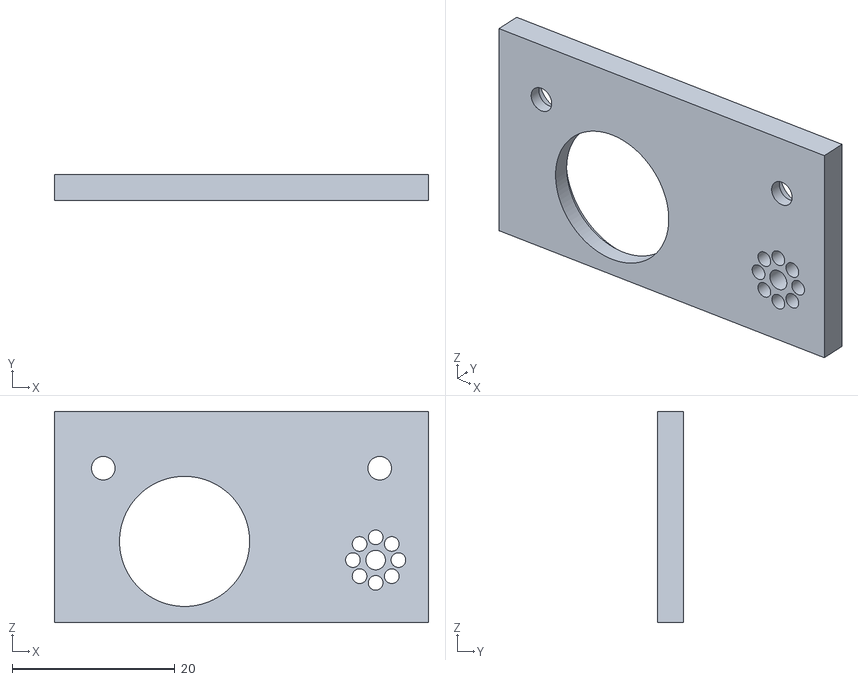
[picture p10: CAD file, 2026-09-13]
hardware/stl/pod_window.stl
46.0 x 3.20 x 26.0

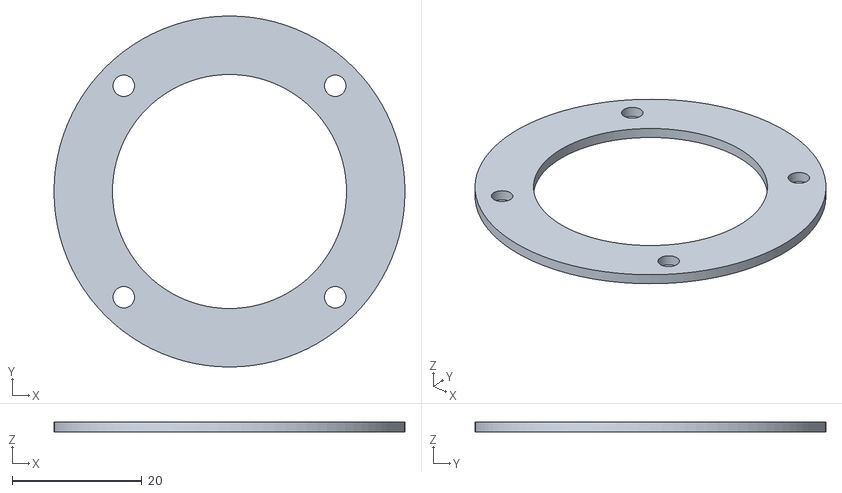
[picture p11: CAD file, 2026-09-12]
hardware/stl/speaker_gasket.stl
54.0 x 54.0 x 1.60

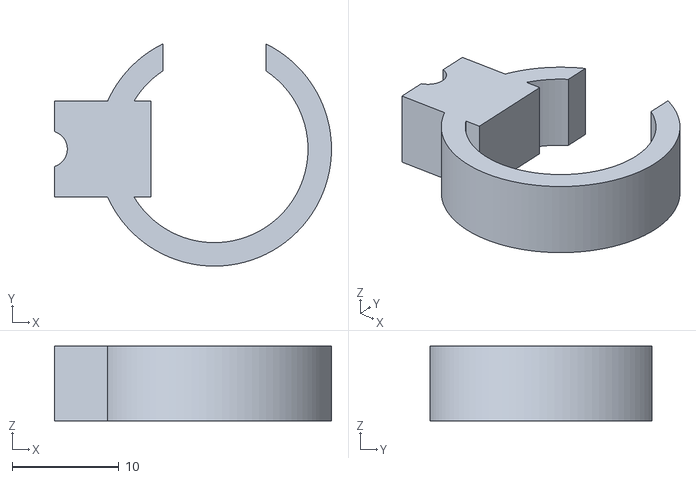
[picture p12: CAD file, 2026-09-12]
hardware/stl/cable_clip.stl
25.9 x 20.8 x 7.00

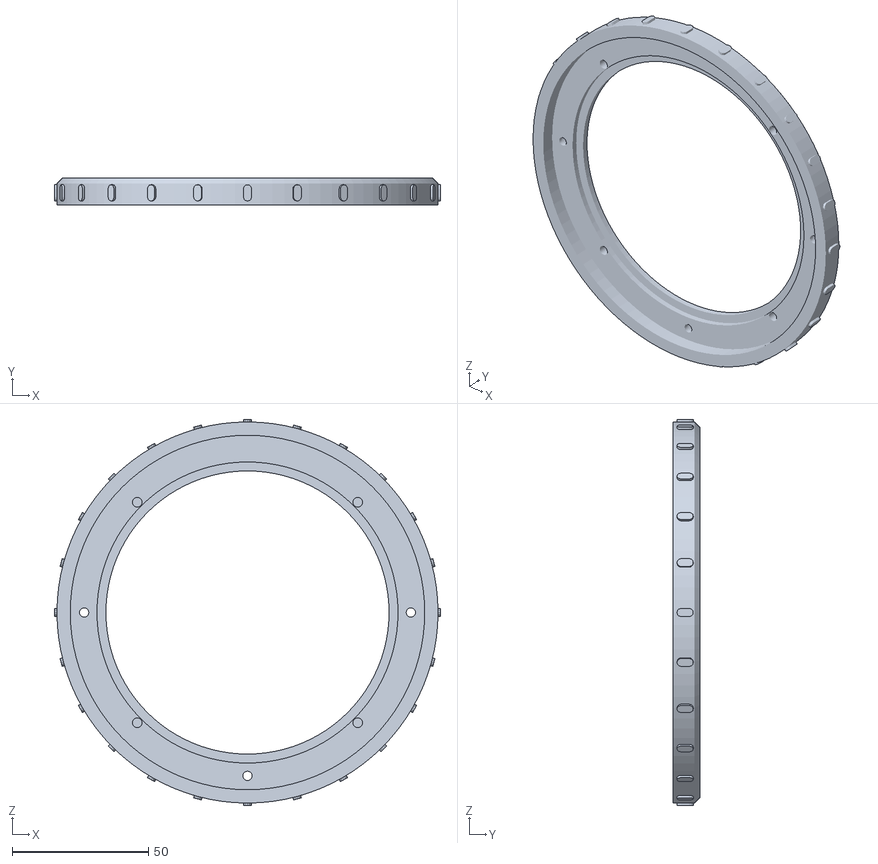
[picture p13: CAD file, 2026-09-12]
hardware/stl/faceplate.stl
141.8 x 10.0 x 141.8

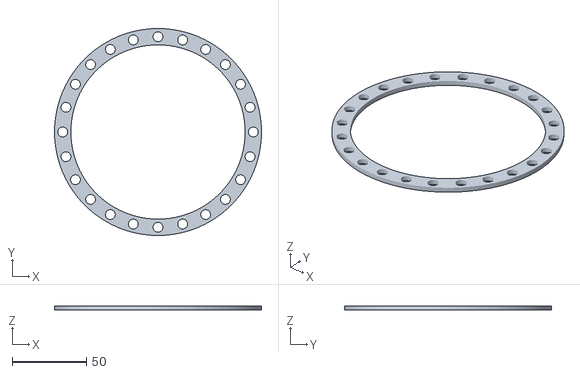
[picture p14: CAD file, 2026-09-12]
hardware/stl/ball_cage.stl
139.0 x 139.0 x 3.00

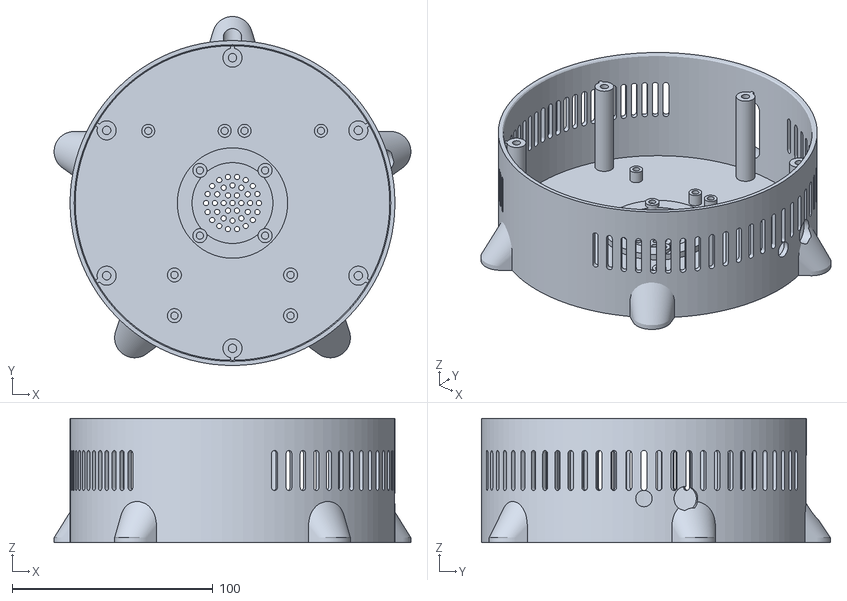
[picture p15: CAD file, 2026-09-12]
hardware/stl/base_shell.stl
177.9 x 174.0 x 62.0

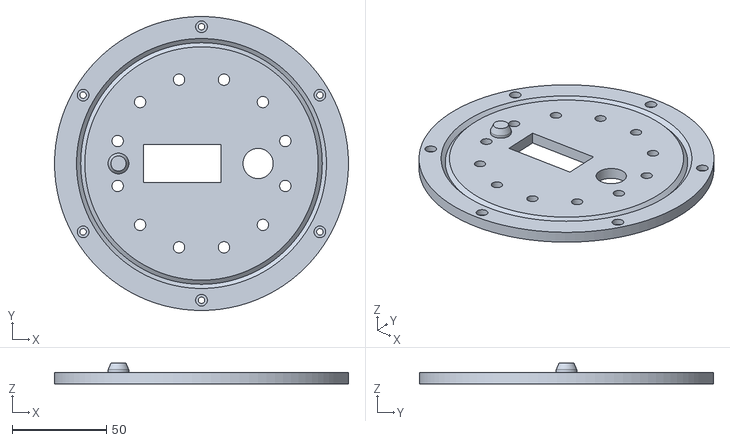
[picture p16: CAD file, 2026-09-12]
hardware/stl/base_deck.stl
155.8 x 155.8 x 11.0

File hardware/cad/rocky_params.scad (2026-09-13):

// =====================================================================
// Rocky - shared dimension library
// ---------------------------------------------------------------------
// EVERY printable part in hardware/cad/ includes this file. Change a
// number here and re-run ./build_all.sh to regenerate the whole robot.
//
// UNITS: millimetres, degrees.
//
// !! BEFORE YOU PRINT !!
// Three groups of numbers below are marked MEASURE. They describe parts
// that ship in slightly different revisions from different vendors (the
// round display module especially). Put calipers on your actual parts
// and correct them, then rebuild. Everything else keys off these.
// =====================================================================

// ---------------------------------------------------------------------
// Print / fit tolerances
// ---------------------------------------------------------------------
wall        = 2.6;   // nominal shell wall (3 perimeters at 0.4mm nozzle)
thin_wall   = 1.8;   // internal ribs and webs
slop        = 0.30;  // clearance on sliding / mating fits
press_slop  = 0.05;  // interference fit (bearings, dowels)
eps         = 0.01;  // co-planar face nudge for clean CSG

// Fastener system: M3 with brass heat-set inserts (M3 x 5.0mm OD x 4.0 long)
m3_free     = 3.4;   // M3 clearance hole
m3_head     = 6.2;   // M3 socket-head cap diameter
m3_head_h   = 3.2;
m3_insert_d = 4.2;   // heat-set pilot bore (melt-in; 4.2 for 5.0 OD inserts)
m3_insert_h = 5.0;
m2_free     = 2.4;   // M2 clearance (display + camera + Pi hardware)
m2_insert_d = 3.2;
m25_free    = 2.9;   // M2.5 clearance (Raspberry Pi mounting)
m25_insert_d= 3.6;

// ---------------------------------------------------------------------
// Overall envelope  (design target: well under 1 cubic foot)
// ---------------------------------------------------------------------
base_d        = 162;   // base outer diameter
base_h        = 62;    // base wall height (desk to turntable underside)
base_floor_t  = 3.0;   // bottom plate thickness

leg_count     = 5;     // Rocky's five limbs
leg_reach     = 13;    // how far a leg sticks out past the base wall
leg_h         = 16;

// ---------------------------------------------------------------------
// Slewing ring: 6 mm balls running in a printed race
// ---------------------------------------------------------------------
ball_d        = 6.0;   // 6mm chrome steel balls (or 6mm airsoft BBs in a pinch)
ball_count    = 24;
race_d        = 128;   // pitch circle the ball centres ride on
// A 90-degree V groove, not a semicircle: it is self-supporting in both
// print orientations and it self-centres the balls on two contact lines.
race_groove_d = 2.2;   // groove depth below the race face
// Ball centre sits ball_d/2/sin(45) above the apex, so the two race faces
// must end up 2*(that - groove depth) apart:
race_gap      = 4.1;   // 2 * (6/2/0.7071 - 2.2) = 4.09

turntable_d   = 150;
turntable_t   = 5.0;

// ---------------------------------------------------------------------
// Servos  -- MEASURE. Standard-size hobby servo, the universal footprint.
// (Hitec HS-5485HB / Savox SH-0255MG / MG996R all match this.)
// ---------------------------------------------------------------------
sv_body_l     = 40.6;  // body length
sv_body_w     = 20.0;  // body width
sv_body_h     = 37.0;  // body height, underside to top of case
sv_flange_l   = 54.5;  // tip to tip across the mounting ears
sv_flange_t   = 2.7;   // ear thickness
sv_flange_z   = 27.2;  // underside of body to underside of ears
sv_hole_dx    = 49.5;  // mounting hole spacing along the long axis
sv_hole_dy    = 10.0;  // hole spacing across
sv_hole_d     = 2.6;   // self-tapping M2.5 into plastic
sv_shaft_off  = 10.2;  // body centre to output shaft centre, along length
sv_shaft_d    = 6.0;   // spline boss outer diameter
sv_boss_h     = 4.0;   // spline boss height above case
sv_horn_d     = 22;    // round horn disc diameter
sv_horn_t     = 2.0;

// ---------------------------------------------------------------------
// Micro servo (tilt axis) -- MEASURE. MG90S / HS-5065MG class.
// A standard-size servo will not fit beside the Pi inside the head, and
// with the head trimmed to balance on its tilt axis a micro has ample
// torque: the servo only fights inertia and friction, never gravity.
// ---------------------------------------------------------------------
msv_body_l    = 23.0;
msv_body_w    = 12.2;
msv_body_h    = 22.5;  // underside of body to top of case
msv_flange_l  = 32.2;
msv_flange_t  = 2.5;
msv_flange_z  = 16.0;  // body underside to underside of the ears
msv_hole_dx   = 27.9;  // single pair of ear holes
msv_hole_d    = 2.2;
msv_shaft_off = 5.9;
msv_shaft_d   = 4.8;
msv_boss_h    = 4.0;
msv_horn_d    = 20.0;
msv_horn_t    = 1.8;

// ---------------------------------------------------------------------
// Sensor brow: the camera pod above the face. Free-standing, so the
// camera board is not fighting the display for room inside the face.
// Its underside is a 45 degree ramp, which keeps it support-free.
// ---------------------------------------------------------------------
pod_w         = 46;    // across X: camera alongside the microphone
pod_z0        = 68;    // where the ramp leaves the head shell
pod_z1        = 100;   // top of the pod
pod_y_front   = 26;    // front face of the pod
pod_wall      = 2.4;
pod_y_rear    = -16;   // rear face of the pod, below the ramp
pod_ramp_z    = 75;    // above this the rear face climbs at 45 degrees
// Rear face of the brow at height z: flat below pod_ramp_z, 45 degrees above.
function pod_ramp_y(z)  = pod_y_rear + max(0, z - pod_ramp_z);
pod_cav_y1    = pod_y_front - pod_wall;      // inner face of the front wall
pod_cav_x     = pod_w/2 - pod_wall;          // inner face of each side wall

// ---------------------------------------------------------------------
// Round display  -- MEASURE. Waveshare 4" DSI Round, 720x720.
// disp_glass_d : outer diameter of the cover glass
// disp_active_d: the lit circle (4" diagonal on a round panel = the dia)
// disp_pcb_*   : the carrier PCB behind the glass
// ---------------------------------------------------------------------
disp_glass_d   = 110.0;
disp_active_d  = 101.6;
disp_glass_t   = 2.2;
disp_pcb_w     = 91.0;
disp_pcb_h     = 91.0;
disp_pcb_t     = 1.6;
disp_stack_t   = 11.5; // glass front face to deepest component on the back
disp_hole_dx   = 81.0; // carrier PCB mounting holes (M2.5, 4 off)
disp_hole_dy   = 81.0;
disp_bezel_ov  = 3.0;  // how far the printed bezel laps over the glass

// ---------------------------------------------------------------------
// Head
// ---------------------------------------------------------------------
y_split       = 21;    // faceplate takes over forward of this plane
rear_ch       = 8;     // 45 degree rear chamfer run
front_ch      = 2;     // chamfer breaking the faceplate rim
head_d        = 140;
head_depth    = 62;
head_face_tilt= 6;     // face tips back this many degrees: reads as "attentive"
// Head coordinate convention: Rocky faces +Y. The face is a circle of
// head_d in the XZ plane; head_depth runs along Y; the tilt axis runs
// along X through the head's centre of mass.
tilt_axis_z   = 170;   // height of the tilt pivot above the desk
yoke_arm_t    = 7.0;   // arm plate thickness, along X
yoke_depth    = 26.0;  // arm / crossbar depth, along Y
yoke_bar_h    = 12.0;  // crossbar height
yoke_clear    = 1.6;   // air gap between head cheek and yoke arm
tilt_range    = 26;    // +/- degrees the software limits allow
// Mechanical tilt end stop: a pin on the inner face of each yoke arm runs in
// an arc slot milled through the head's cheek. Both parts read these numbers,
// so the slot and the pin cannot drift apart.
//
// The stop sits tilt_stop_over degrees OUTSIDE tilt_range on purpose. Software
// is the working limit; the stop is the backstop behind it, and a servo that
// grinds against its end stop on every full-travel command is a servo that
// strips. MECHANICAL_LIMITS in software/rocky/motion/kinematics.py holds
// tilt_range, not tilt_range + tilt_stop_over.
tilt_stop_over = 4;    // degrees of slack beyond tilt_range
tilt_stop_d    = 5.0;  // pin diameter
// The pin sits against the BACK face of the arm, not on its centreline: the
// yoke prints on its back, so a peg there lies on the bed instead of starting
// in mid-air 13 mm up.
tilt_stop_y    = -(yoke_depth/2 - tilt_stop_d/2);   // pin axis, head frame
tilt_stop_z    = -30;                               // pin axis, head frame
// Where that pin crosses the shell: the cheek is a cylinder of head_d about
// the Y axis, so the slot's depth below the surface follows from its z alone.
function tilt_stop_surface_x(z) = sqrt(pow(head_d/2, 2) - pow(z, 2));
pan_range     = 100;   // +/- degrees; hard stop in the base limits it
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

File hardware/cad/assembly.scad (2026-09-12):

// =====================================================================
// Rocky | assembly preview
// Imports the exported STLs and places them in the robot's own frame,
// z = 0 at the desk surface. Set pan / tilt to check clearances through
// the full range of motion before you print anything.
//
//   openscad -o preview.png --camera=0,0,130,65,0,25,700 assembly.scad
// =====================================================================
include <rocky_params.scad>
use     <rocky_lib.scad>

pan  = 0;    // degrees, +/- pan_range
tilt = 0;    // degrees, +/- tilt_range
show_balls = true;

S = "../stl/";

color("#3b4252") import(str(S, "base_shell.stl"));
color("#4c566a") translate([0, 0, deck_z]) import(str(S, "base_deck.stl"));

rotate([0, 0, pan]) {
    color("#4c566a") translate([0, 0, turn_z]) import(str(S, "turntable.stl"));
    color("#3b4252") translate([0, 0, yoke_base_z]) import(str(S, "yoke.stl"));

    translate([0, 0, tilt_axis_z]) rotate([tilt, 0, 0]) {
        color("#3b4252") import(str(S, "head_back.stl"));
        color("#d8dee9") import(str(S, "faceplate.stl"));
        color("#2e3440") translate([0, pod_y_front + 1.6, pod_z1 - 13])
            rotate([0, 0, 0]) import(str(S, "pod_window.stl"));
        // the display itself, so the face reads at a glance
        color("#88c0d0") translate([0, head_depth/2 - 2.4 - disp_glass_t/2, 0])
            rotate([-90, 0, 0]) cylinder(d = disp_active_d, h = 0.8, center = true);
    }
}

if (show_balls)
    color("#bf616a") translate([0, 0, race_z + race_gap/2]) race_balls();

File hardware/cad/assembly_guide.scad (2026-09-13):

// =====================================================================
// Rocky | assembly figures
//
// Renders the pictures used in docs/ASSEMBLY.md. One file so that every
// figure is drawn from the same part positions - if a dimension changes
// in rocky_params.scad, every figure moves with it.
//
//   openscad -o out.png -D 'VIEW="exploded"' assembly_guide.scad
//
// render_figures.sh drives it for all views.
// =====================================================================
include <rocky_params.scad>
use     <rocky_lib.scad>
use     <components.scad>

VIEW    = "exploded";
EXPLODE = 1.0;        // 0 is fully assembled
SHOW_COMPONENTS = true;
CAM_RX  = 62;         // must match the camera the shell script uses,
CAM_RZ  = 205;        // so the labels face the viewer
LABEL_D = 150;        // callout length, scaled per figure so labels stay in frame

S = "../stl/";

// Printed parts keep the colours used in the rest of the documentation.
C_SHELL = "#3b4252";
C_DECK  = "#4c566a";
C_FACE  = "#d8dee9";
C_BALL  = "#bf616a";

// ---------------------------------------------------------------------
// labels
// ---------------------------------------------------------------------

module billboard(txt, size = 7, colour = "#e5e9f0") {
    color(colour) rotate([0, 0, CAM_RZ]) rotate([CAM_RX, 0, 0])
        linear_extrude(0.8)
            text(txt, size = size, font = "Liberation Sans:style=Bold",
                 halign = "left", valign = "center");
}

// The world direction that appears to run left-to-right on screen, given
// the camera's Z rotation. Callouts travel along it so their leader lines
// look horizontal in the rendered image rather than diving into the page.
SCREEN_X = [cos(CAM_RZ), sin(CAM_RZ), 0];

function screen_offset(d) = [SCREEN_X[0] * d, SCREEN_X[1] * d, 0];

// A numbered callout with a leader line back to the part it names.
//
// Only the NUMBER is drawn. Long labels ran off the edge of every figure at
// small scales, and a number plus a legend is how technical illustration
// solves that anyway. The caption text is echoed instead, and the render
// script captures it into a legend file beside the image - so the figure and
// its caption come from this one place and cannot drift apart.
//
// Positive `side` puts the number to the right of the part, negative to left.
module callout(n, txt, at, side = 1, rise = 0, size = 0) {
    echo(str("LEGEND|", n, "|", txt));
    d = side * LABEL_D;
    r = LABEL_D * 0.105;                       // number disc scales with the figure
    tip = [at[0] + SCREEN_X[0] * d, at[1] + SCREEN_X[1] * d, at[2] + rise];
    color("#88c0d0") hull() {
        translate(at) sphere(d = r * 0.36, $fn = 8);
        translate(tip) sphere(d = r * 0.22, $fn = 8);
    }
    color("#88c0d0") translate(at) sphere(d = r * 0.52, $fn = 14);
    translate(tip) rotate([0, 0, CAM_RZ]) rotate([CAM_RX, 0, 0]) {
        color("#88c0d0") cylinder(r = r, h = 0.6, $fn = 32);
        translate([0, 0, 0.6]) color("#111820") linear_extrude(0.6)
            text(str(n), size = r * 1.25, font = "Liberation Sans:style=Bold",
                 halign = "center", valign = "center");
    }
}

module title(txt, at = [0, 0, 0]) {
    translate(at) rotate([0, 0, CAM_RZ]) rotate([CAM_RX, 0, 0])
        color("#eceff4") linear_extrude(0.8)
            text(txt, size = 15, font = "Liberation Sans:style=Bold",
                 halign = "center", valign = "center");
}

// ---------------------------------------------------------------------
// printed parts, each at its assembled height plus an explode offset
// ---------------------------------------------------------------------

function ex(d) = d * EXPLODE;

module p_base()      { color(C_SHELL) import(str(S, "base_shell.stl")); }
module p_deck()      { color(C_DECK)  translate([0,0,deck_z + ex(46)])  import(str(S, "base_deck.stl")); }
module p_turntable() { color(C_DECK)  translate([0,0,turn_z + ex(96)]) import(str(S, "turntable.stl")); }
module p_cage()      { color("#5e81ac") translate([0,0,race_z - 0.5 + ex(74)]) import(str(S, "ball_cage.stl")); }
module p_balls()     { color(C_BALL)  translate([0,0,race_z + race_gap/2 + ex(74)]) race_balls(); }
module p_yoke()      { color(C_SHELL) translate([0,0,yoke_base_z + ex(132)]) import(str(S, "yoke.stl")); }

module head_group(tilt = 0) {
    translate([0, 0, tilt_axis_z + ex(178)]) rotate([tilt, 0, 0]) children();
}

module p_head_back()  { color(C_SHELL) import(str(S, "head_back.stl")); }
module p_faceplate()  { color(C_FACE)  translate([0, ex(62), 0]) import(str(S, "faceplate.stl")); }
module p_pod_window() { color("#2e3440") translate([0, pod_y_front + 1.6 + ex(86), pod_z1 - 13]) import(str(S, "pod_window.stl")); }

// ---------------------------------------------------------------------
// bought-in parts, in their real places
// ---------------------------------------------------------------------

module c_base_electronics() {
    // speaker, magnet up, firing down through the floor grille
    translate([0, 0, base_floor_t]) speaker_40mm();
    translate([0, -46, base_floor_t + 6]) pca9685();
    translate([-23, 36, base_floor_t + 6]) buck_regulator();
    translate([25, 36, base_floor_t + 6]) buck_regulator();
}

module c_pan_servo() {
    translate([0, 0, pan_servo_z]) standard_servo();
    translate([0, 0, boss_top_z - sv_horn_t]) servo_horn();
}

module c_head_internals() {
    // Pi 5, portrait, component side forward, shifted +X to clear the tilt servo
    translate([-10, -22, 0]) rotate([-90, 0, 0]) rotate([0, 0, 90]) raspberry_pi_5();
    // tilt servo on the left cheek, shaft outward through the wall
    translate([-(head_d/2 - wall), 0, 0]) rotate([0, -90, 0]) rotate([0, 0, -90]) micro_servo();
    // camera and microphone in the sensor brow
    translate([-7, 18, 84]) rotate([-90, 0, 0]) camera_module_3();
    translate([mic_x0, mic_y0, mic_z0]) usb_microphone();
    // I2S amplifier on the rear wall, above the Pi
    translate([0, -22, 47]) rotate([-90, 0, 0]) max98357a();
    // the pivot bearing on the right cheek
    translate([head_d/2 + yoke_clear + 1, 0, 0]) rotate([0, 90, 0]) bearing_623();
}

module c_display() {
    translate([0, head_depth/2 - 2.4, 0]) rotate([-90, 0, 0]) round_display();
}

// ---------------------------------------------------------------------
// figures
// ---------------------------------------------------------------------

module fig_exploded() {
    callout(1, "base_shell", [0, 0, 34], -1);
    callout(2, "base electronics", [0, -30, 12], 1, 16);
    callout(3, "pan servo", [0, 0, pan_servo_z + 20], 1, -36);
    callout(4, "base_deck (fixed race)", [0, 0, deck_z + ex(46) + 3], -1);
    callout(5, "ball cage + 24 balls", [60, 0, race_z + ex(74)], -1, -6);
    callout(6, "turntable (rotating race)", [0, 0, turn_z + ex(96) + 8], -1, 16);
    callout(7, "yoke", [66, 0, yoke_base_z + ex(132) + 40], 1);
    callout(8, "head_back + Pi + tilt servo", [0, -40, tilt_axis_z + ex(178)], 1, 46);
    callout(9, "display + faceplate", [0, 40, tilt_axis_z + ex(178) - 20], -1, -8);

    p_base();
    if (SHOW_COMPONENTS) { c_base_electronics(); c_pan_servo(); }
    p_deck();
    p_cage();
    p_balls();
    p_turntable();
    p_yoke();
    head_group() {
        p_head_back();
        if (SHOW_COMPONENTS) { c_head_internals(); c_display(); }
        p_faceplate();
        p_pod_window();
    }
}

module fig_assembled(tilt = 0, pan = 0) {
    p_base();
    p_deck();
    p_balls();
    rotate([0, 0, pan]) {
        p_turntable();
        p_yoke();
        head_group(tilt) { p_head_back(); p_faceplate(); p_pod_window(); }
    }
}

// One point along the harness service loop: a slack helix that winds and
// unwinds as the head turns. Functions cannot be declared inside a for body
// in OpenSCAD, so it lives here.
function harness_point(t) =
    let (a = 40 + t * 640, rr = 34 - 6 * sin(t * 360))
        [rr * cos(a), rr * sin(a), 16 + t * 30];

// --- stage figures, one per step in docs/ASSEMBLY.md ------------------

module fig_stage2() {                       // base electronics, looking in
    callout(1, "speaker, magnet up", [0, 0, 14], -1, 0);
    callout(2, "PCA9685 servo driver", [0, -46, 12], 1, 0);
    callout(3, "5.1V regulator, feeds the Pi", [-23, 36, 14], -1, 0);
    callout(4, "6.0V regulator, feeds the servos", [25, 36, 14], 1, 0);
    p_base();
    c_base_electronics();
}

module fig_stage3() {                       // pan servo hung from the deck
    callout(1, "servo ears bolt UP into the deck", [-18, 0, deck_z - 4], -1, 16);
    callout(2, "body passes through the cutout", [-10, 0, 40], 1, -12);
    callout(3, "spline boss, horn goes here", [0, 0, boss_top_z], 1, 26);
    difference() {
        color(C_DECK) translate([0, 0, deck_z]) import(str(S, "base_deck.stl"));
        // half section, so you can see the servo hanging underneath
        translate([0, 120, deck_z + 6]) cube([400, 200, 40], center = true);
    }
    c_pan_servo();
}
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

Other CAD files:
hardware/cad/ball_cage.scad
hardware/cad/base_deck.scad
hardware/cad/base_shell.scad
hardware/cad/cable_clip.scad
hardware/cad/components.scad
hardware/cad/faceplate.scad
hardware/cad/head_back.scad
hardware/cad/pod_window.scad
hardware/cad/rocky_lib.scad
hardware/cad/speaker_gasket.scad
hardware/cad/turntable.scad
hardware/cad/yoke.scad

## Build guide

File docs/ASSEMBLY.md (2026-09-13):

# Assembly

About four hours if the printing and soldering are already done. Work in the
order below — several steps become awkward or impossible if done later.

**Before you start:** get the electronics working on the bench first, following
[WIRING.md](WIRING.md), with `rocky check` reporting real backends. Debugging a
ribbon cable inside a closed head is miserable; debugging one on the desk is
five minutes.

You will need: hex drivers, a small screwdriver, side cutters, a soldering iron
with a heat-set insert tip, calipers, and grease.

**At the bench:** open [bench-guide.html](bench-guide.html) on your phone. It is
this document as one stage at a time, with the figures, the fastener list for
each stage, and steps you can tick off as you go.

<!-- figure:exploded -->
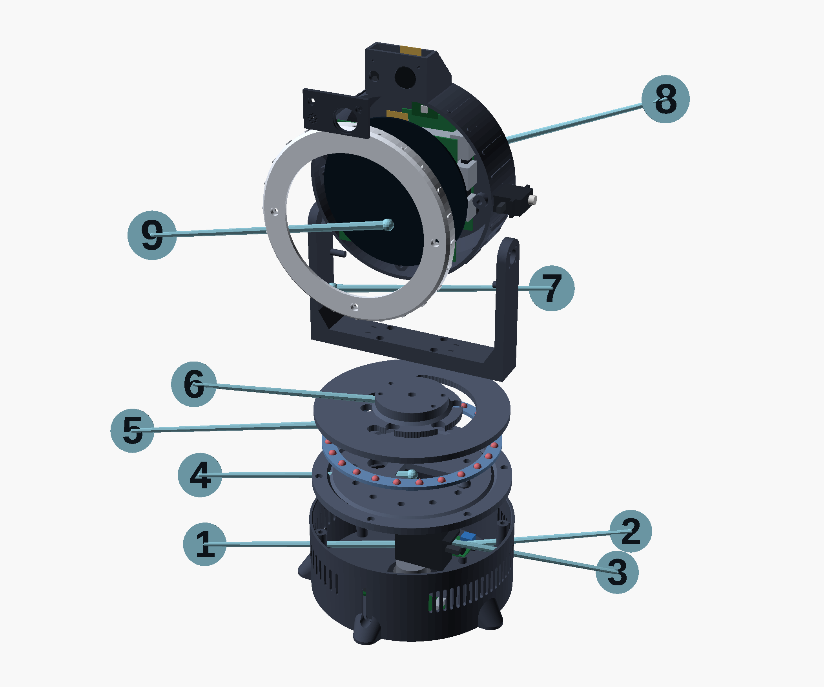
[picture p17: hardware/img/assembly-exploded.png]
Rocky, exploded


**1.** base_shell  
**2.** base electronics  
**3.** pan servo  
**4.** base_deck (fixed race)  
**5.** ball cage + 24 balls  
**6.** turntable (rotating race)  
**7.** yoke  
**8.** head_back + Pi + tilt servo  
**9.** display + faceplate
<!-- /figure -->

Every figure below is generated from the same CAD as the printed parts, so
what you see is what you will be holding. If you change a dimension, re-run the
chain in [hardware/README.md](../hardware/README.md) and every picture in this
document follows.

---

## Stage 1 — Prepare the printed parts

Do every heat-set insert now, in one session with the iron hot. Going back for
one forgotten insert after wiring means undoing work.

| Part | Inserts | Where |
|---|---|---|
| `base_shell` | 6 × M3 | tops of the tall deck bosses |
| `base_shell` | 4 × M2.5 | speaker mounting pads |
| `base_shell` | 4 × M2.5 | PCA9685 pads |
| `base_shell` | 4 × M2.5 | regulator pads |
| `base_deck` | 4 × M2.5 | **underside**, for the pan servo's ears |
| `turntable` | 4 × M3 | hub top, for the yoke |
| `head_back` | 4 × M2.5 | Pi standoffs |
| `head_back` | 3 × M3 | faceplate posts |
| `head_back` | 1 × M3 | right cheek, the tilt pivot |
| `head_back` | 1 × M3 | trim-weight post, rear |
| `head_back` | 2 × M2 | amplifier pads, rear wall |
| `head_back` | 4 × M2 | camera posts inside the brow |
| `faceplate` | 4 × M2.5 | display carrier bosses |

Three things in this robot take no insert at all. The tilt servo's two ear
screws and `pod_window`'s two go straight into printed bosses as self-tappers —
the brow's front wall is 2.4 mm and there is no printable way to thicken it
from inside, which is far more material than a thread-forming screw needs and
far less than a heat-set insert wants. And the microphone takes no fastener:
it drops into a slot moulded into the brow.

Check every one by hand-threading a screw before moving on.

---

## Stage 2 — The base electronics

<!-- figure:stage2 -->
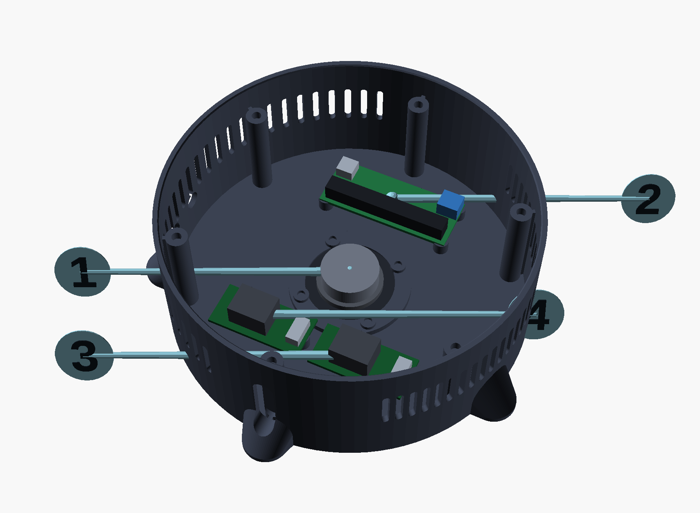
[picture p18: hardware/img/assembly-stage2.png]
Stage 2 — the base electronics


**1.** speaker, magnet up  
**2.** PCA9685 servo driver  
**3.** 5.1V regulator, feeds the Pi  
**4.** 6.0V regulator, feeds the servos
<!-- /figure -->

Build this as a subassembly, on the bench, before anything goes into the shell.

1. **Speaker.** Lay the TPU gasket on the base floor's raised ring, put the
   speaker on it facing **down** through the grille, and fix it with four M2.5 ×
   10 screws. Snug, not tight — over-tightening distorts the frame and the
   speaker buzzes.
2. **Speaker leads.** Solder a pair of 22 AWG silicone leads to the speaker's
   terminals, long enough to reach up through the pan joint. The amplifier is
   in the head, not down here — see Stage 6 — so these two conductors are part
   of the harness.
3. **Regulators.** Buck A and Buck B onto their pads with M2.5 × 6.
   **Set both output voltages now**, before anything is connected downstream —
   5.1 V and 6.0 V. This is the last comfortable moment to do it.
4. **Servo driver.** PCA9685 onto its pads with M2.5 × 6. Solder the 470 µF
   capacitor across the screw terminal, minding polarity.
5. **Panel parts.** DC jack and switch into the base wall from the inside,
   wired through the fuse holder per [WIRING.md](WIRING.md).
6. **Test.** Power up. Both rails correct, `i2cdetect` finds `0x40`. Do not
   proceed until it does.

---

## Stage 3 — Pan servo and race deck

<!-- figure:stage3 -->
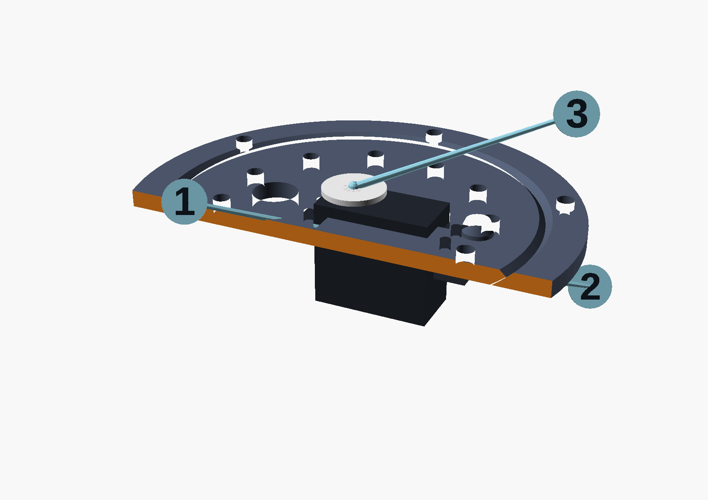
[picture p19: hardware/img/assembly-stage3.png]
Stage 3 — the pan servo hangs from the deck


**1.** servo ears bolt UP into the deck  
**2.** body passes through the cutout  
**3.** spline boss, horn goes here
<!-- /figure -->

The pan servo hangs from the deck rather than standing on the floor. It means
the head's weight goes straight through the slew ring into the base wall, and it
removes a bracket.

1. Set the servo to its **centre** before fitting it. Either run
   `rocky calibrate pan` with the servo on the bench, or move it gently by hand
   to the middle of its travel and count turns to each end.
2. Offer the servo up to the deck's **underside**, body passing through the
   rectangular cutout, output shaft up. The ears sit flat against the deck.
3. Four M2.5 × 10 up through the ears into the deck's inserts. Snug.
4. Route the servo lead to channel `0` on the PCA9685.
5. Lower the deck into the base shell so it lands on the six bosses, race groove
   **up**. Six M3 × 12, counterbored from above so the heads sit below the race
   face.

Check: the deck should sit flat and not rock. If it does, one boss printed
proud — sand it rather than forcing the screws.

---

## Stage 4 — The slew ring

<!-- figure:stage4 -->
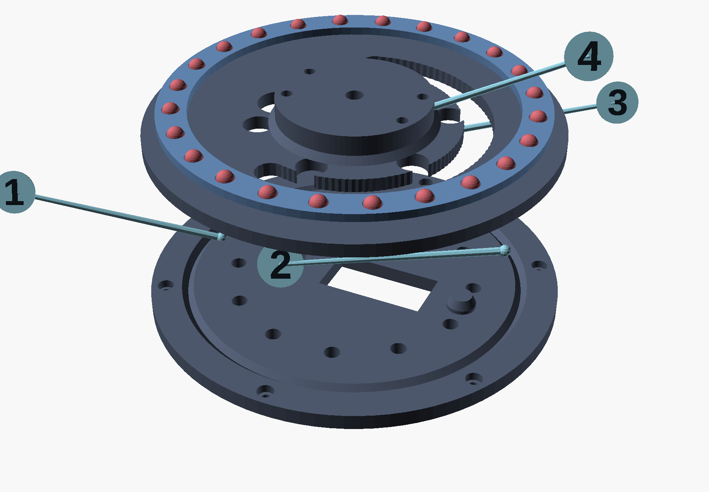
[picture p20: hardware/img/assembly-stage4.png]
Stage 4 — the slew ring


**1.** grease the V groove, thinly  
**2.** cage sets the ball spacing  
**3.** 24 x 6mm steel balls  
**4.** horn screws up into the hub
<!-- /figure -->

This is the joint Rocky turns on and the one place where a few minutes of care
pays back every time it moves.

1. Wipe both race grooves clean. Any stray strand of filament will be audible
   forever.
2. Put a **thin** film of PTFE or lithium grease in the deck's groove. Thin — a
   thick bead collects dust and drags.
3. Drop the `ball_cage` into the groove so its 24 holes sit over the race.
4. Place one 6 mm ball into each hole. They will sit in the greased V.
5. Fit the **servo horn** to the turntable: a round horn into the recess in the
   hub's underside, four small self-tappers up into the hub.
6. Lower the turntable onto the balls, aligning the horn with the servo's
   spline. Rotate it slowly by hand until the splines engage and it seats.
7. Through the 6.5 mm access hole in the top of the hub, drive the servo's own
   centre screw into the shaft. **This is what stops the head lifting off** —
   there is no other axial retention.
8. Turn the head by hand, both ways. It should be smooth and near-silent, and
   stop firmly against the printed post at about ±106° — a little outside the
   ±100° software limit, so the servo never reaches it under power.

If it grinds, there is too much grease or a ball is out of its pocket. If it
rocks, a ball is missing.

---

## Stage 5 — The yoke

<!-- figure:stage5 -->
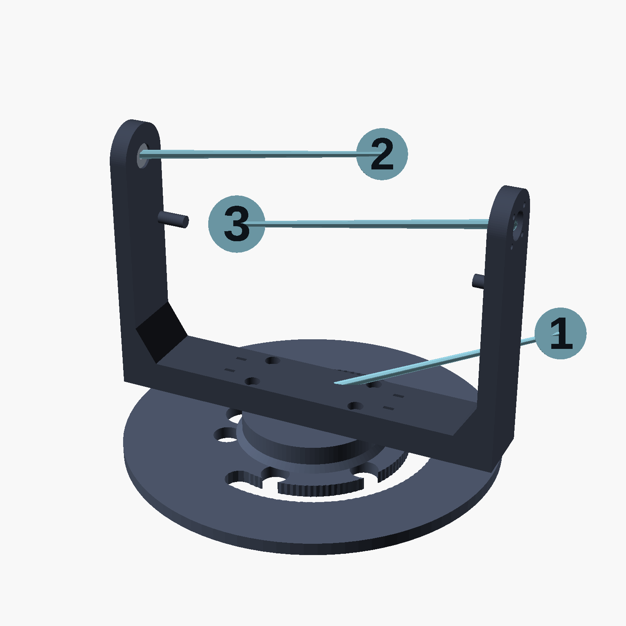
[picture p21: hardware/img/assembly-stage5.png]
Stage 5 — the yoke


**1.** 4 x M3 x 16 into the hub  
**2.** 623ZZ bearing, press fit  
**3.** tilt servo horn fits here
<!-- /figure -->

1. Sit the yoke on the turntable hub, crossbar down, arms up.
2. Four M3 × 16 down through the crossbar's counterbores into the hub's
   inserts. Tighten evenly.
3. Press the **623ZZ bearing** into the pocket on the inside face of the *right*
   arm. It is an interference fit — press it square with a vice or a flat block,
   not a hammer.

Leave the left arm alone for now; the tilt servo horn is fitted at Stage 8.

---

## Stage 6 — The head

<!-- figure:stage6 -->
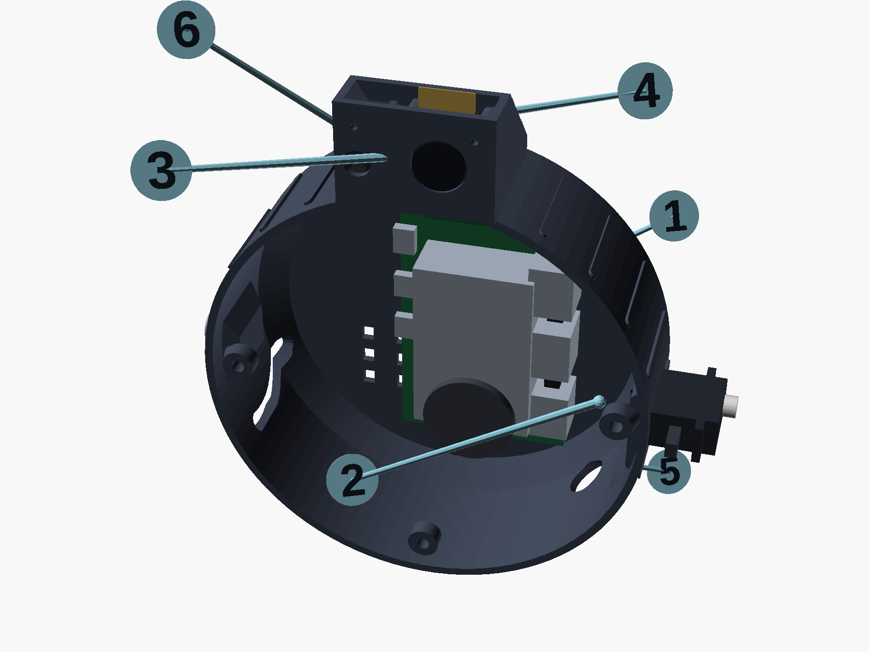
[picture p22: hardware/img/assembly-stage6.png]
Stage 6 — inside the head


**1.** Pi 5, portrait, offset right  
**2.** tilt servo, shaft through the cheek  
**3.** camera in the brow  
**4.** microphone  
**5.** trim weights balance the head  
**6.** I2S amplifier
<!-- /figure -->

Everything except the faceplate goes in through the open front — except in the
brow, which is closed at the front and open at the top. The camera and the
microphone drop in from above, and `pod_window` then goes on the outside of the
brow's front face as a bezel over the lens and mic bores rather than as a lid.

1. **Tilt servo.** Centre it first, the same way you centred the pan servo.
   Fit it against the pad on the **left** inner cheek, output boss through the
   11 mm hole so the spline protrudes outside the shell. Two M2 × 8
   self-tappers through its ears into the pad. Route its lead down to the
   harness.
2. **Raspberry Pi.** Four M2.5 × 6 onto the four posts rising from the rear
   wall, active cooler already fitted. The board sits portrait, offset to the
   right to clear the tilt servo. Connect the cooler's fan to its header.
3. **Ribbon cables.** Camera cable into `CAM/DISP 0`, display cable into
   `CAM/DISP 1`, blue stiffeners facing away from the board. Leave the far ends
   loose for now. The camera's end reaches the brow through the slot in the
   brow's floor, which is also where the microphone's lead comes down.
4. **Camera.** Four M2 × 6 onto the posts inside the brow, lens pointing
   forward. Connect the camera end of its ribbon.
5. **Microphone.** No bracket and no screws. The flat USB stick goes in on
   edge, capsule forward, USB plug towards the back, and drops straight down
   into the slot to the right of the camera until it clicks past the nub at the
   slot's mouth. Its front face then sits against the brow's front wall, behind
   that wall's port and the rosette of holes in `pod_window`. Route the USB
   lead down through the slot in the brow's floor to the Pi — use the
   right-angle adapter, a straight plug fouls the shell.

   It is a deliberate friction fit, so it wants a firm push, not force. If it
   will not go, you have the wrong microphone: the slot is cut for the flat
   commodity stick in [BOM](BOM.md) item 5.3, 22.2 × 18.3 × 7.0 mm, and
   `mic_body_x/y/z` in `rocky_params.scad` are what you change to fit another.
6. **Amplifier.** Two M2 × 6 onto the pads on the rear wall, above the Pi.
   Wire I²S and 5 V to it from the header per [WIRING.md](WIRING.md), and its
   speaker output down through the harness to the base.

   It sits up here rather than beside the speaker so that two analogue
   conductors cross the rotating joint instead of five digital ones. BCLK
   toggles at about 3 MHz; a flexing harness is not where you want that.
7. **Brow window.** `pod_window` flat onto the brow's front face, counterbores
   outward, two M2.5 × 8 self-tappers. Its lens aperture and mic rosette line
   up with the two bores through the wall behind them; the lens barrel stands
   in its aperture and should not touch it.
8. **Power and harness.** Bring the harness in through the 14 mm hole at the
   lower right of the shell. 5.1 V to the Pi's USB-C, I²C and tilt-servo
   conductors down to the base.

---

## Stage 7 — The faceplate

<!-- figure:stage7 -->
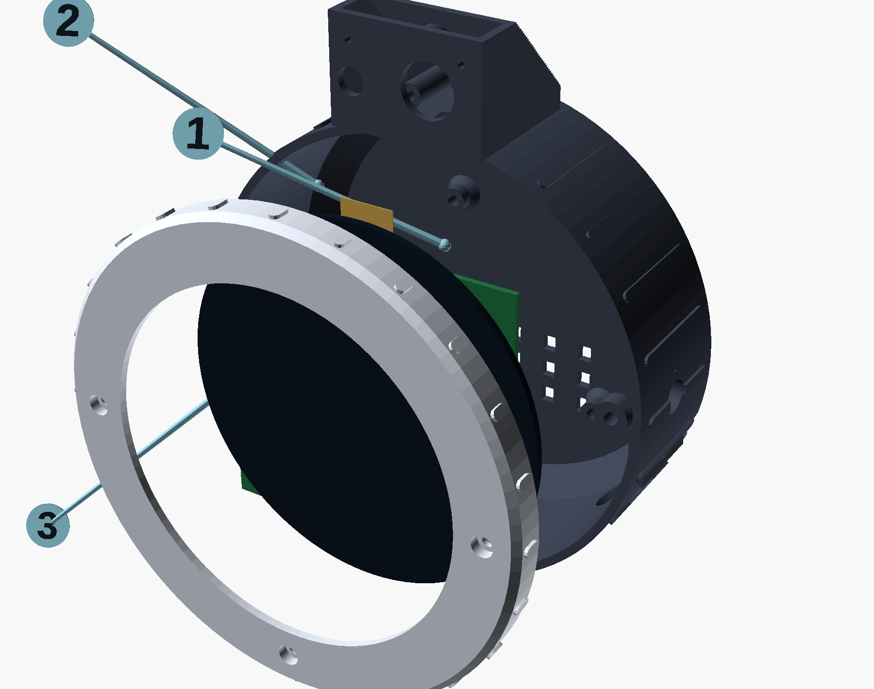
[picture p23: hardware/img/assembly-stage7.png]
Stage 7 — display and faceplate


**1.** display drops in from behind  
**2.** 4 x M2.5 into the faceplate  
**3.** 3 x M3 through the rim
<!-- /figure -->

1. Lay the faceplate face-down on something soft.
2. Drop the display module into the pocket from behind, glass forward against
   the bezel's lip. It should sit flat with a little clearance all round. If it
   fouls, correct `disp_glass_d` in `rocky_params.scad` and reprint — do not
   file the pocket, it will show through the bezel.
3. Four M2.5 × 6 through the carrier's holes into the faceplate's inserts.
   Gentle: you are clamping glass.
4. Connect the display ribbon.
5. Offer the faceplate to the head, feeding slack ribbon back inside, and fix it
   with three M3 × 16 through the rim into the posts at 3, 9 and 6 o'clock.

The three screw heads are visible on Rocky's face. That is intentional.

---

## Stage 8 — Join the head to the yoke

Two people is easier. One to hold, one to drive screws.

1. Lower the head between the arms so the tilt servo's spline enters the
   **left** arm's recess and the **right** cheek's insert lines up with the
   bearing.
2. **Right side:** M3 × 20 from outside the right arm, through the bearing,
   into the head's insert. Tighten until snug — the bearing's inner race should
   clamp against the head, and the outer race should still turn freely.
3. **Left side:** with the head level and the tilt servo still centred, fit the
   round horn into the arm's recess and drive four M2 × 8 from **outside** the
   arm into the horn.

   Get this right the first time: the horn's splines set where "level" is. If
   the head ends up cocked, pull the four screws, lift the horn off one spline,
   and refit. Small trims are easier in software —
   `motion.tilt.centre_trim_deg`.
4. Tip the head through its full travel by hand. It should move freely, and
   each yoke pin should come up against the end of its slot in the cheek at
   about ±31°, with the crossbar clearing the head's lower corners at full
   tilt.

   ±31°, not ±26°: the software limit is ±26, and the printed stop sits five
   degrees outside it on purpose. Software is the working limit; the stop is
   the backstop behind it, and a servo that grinds into its end stop on every
   full-travel command is a servo that strips. You should not be able to reach
   the pins under power — if you can, the limits in `config.toml` are wrong.

---

## Stage 9 — Balance the head

**Do not skip this.** The tilt axis is meant to run through the head's centre of
mass. Balanced, the tilt servo only fights inertia and friction, which is what
makes a micro servo sufficient and what stops it humming and drifting. Nose-
heavy, it works against gravity continuously, gets hot, and buzzes.

1. Switch the servos off: `rocky run --sim` in another terminal, or just leave
   the robot unpowered and disconnect the tilt servo lead.
2. Hold the yoke and let the head hang free on its pivot.
3. It will almost certainly tip forward — the display is the heaviest thing in
   there and it is all at the front.
4. Stack M8 washers on an M3 screw into the trim post at the lower rear of the
   head shell. Add until the head sits level on its own and stays wherever you
   put it.
5. Ten washers is typical, around 30 g. If you need more than about twenty,
   something else is wrong — check the Pi is on its posts and not resting
   forward.

---

## Stage 10 — Close up and calibrate

<!-- figure:harness -->
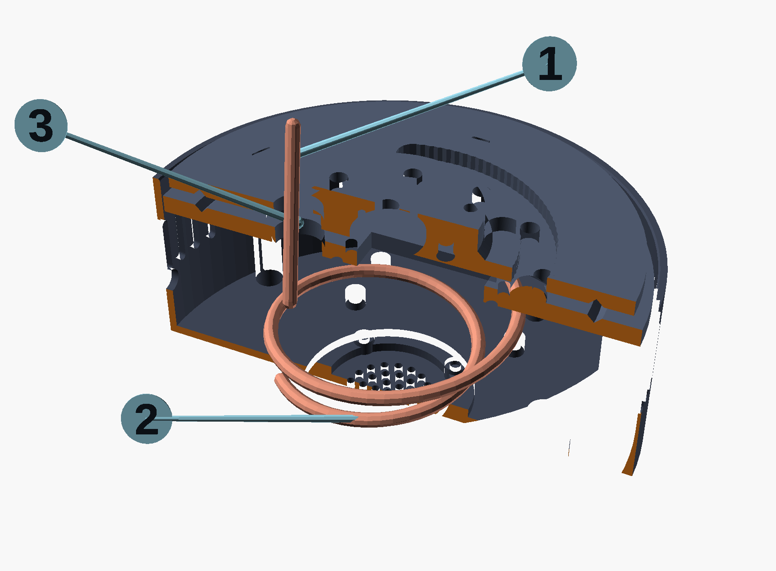
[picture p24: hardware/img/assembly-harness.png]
The pan-joint harness


**1.** 11 conductors cross the joint  
**2.** service loop, about 60mm slack  
**3.** 16mm bore at 30mm radius
<!-- /figure -->

1. Dress the harness with the four `cable_clip` pieces. Check the service loop
   coils and uncoils across the full pan range without pulling or snagging.
2. Felt pads under the five legs.
3. Power up.

```bash
rocky check                # every backend should say "ok", not "sim"
rocky calibrate pan        # a/d nudge, s saves
rocky calibrate tilt
```

Calibration writes `centre_trim_deg` into `config.toml`. It is far easier than
getting the horn splines mechanically perfect, and it is what the tool is for.

4. Start Rocky and open the dashboard:

```bash
rocky run
# http://<your-pi>:8080
```

5. On the **Motion** tab, jog both axes to their limits and watch that nothing
   fouls. On the **Expression** tab, click through the faces. On **Voice**,
   play a test tone and a few chords.

That is Rocky finished.

<!-- figure:assembled -->
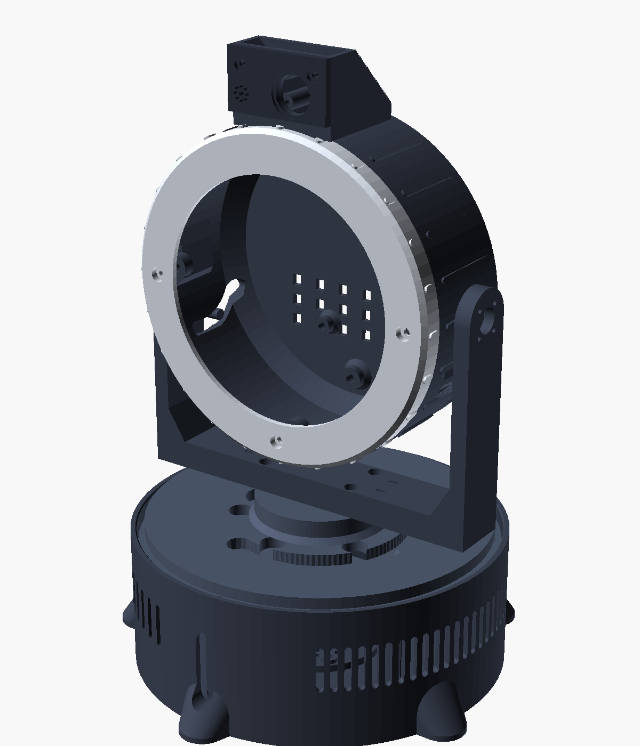
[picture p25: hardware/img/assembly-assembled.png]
Assembled

<!-- /figure -->

---

## If something is wrong

| Symptom | Usually |
|---|---|
| An axis moves the wrong way | Set `motion.<axis>.invert = true`. |
| The head sits off-centre | `rocky calibrate`, do not adjust the horn. |
| A servo buzzes constantly at rest | Normal for digital servos. Lower `motion.idle_torque_off_s`. If it persists while driving, the head is out of balance — back to Stage 9. |
| The head drifts down over time | Out of balance, or the tilt horn screws are loose. |
| Rocky turns the wrong way to look at you | `vision.h_fov_deg` does not match your lens. |
| Rocky overshoots then corrects back | `motion.tracking.gain` too high. Try 0.4. |
| Grinding when turning | Grease or a stray ball in the race. Open Stage 4 and look. |
| The face is blank | The display overlay. `dmesg \| grep -i dsi`, and check the ribbon is fully seated. |
| The camera enumerates but returns nothing | Camera ribbon in the display socket, or not fully seated. |
| Rocky answers its own sentences | The microphone is hearing the speaker and `_speaking` gating is not working — check `rocky check` shows a real audio backend. |
| Rocky moves and chirps but never talks | No `ANTHROPIC_API_KEY`, or no speech engine. `rocky check` says which. |

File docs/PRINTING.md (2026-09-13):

# Printing

Eleven parts, about **625 cm³** of plastic — roughly 780 g in PETG. Budget two
days of printer time. Nothing needs supports except the sensor brow, and only a
little there.

## Settings

Sensible defaults for a 0.4 mm nozzle:

| Setting | Value | Why |
|---|---|-----|
| Layer height | 0.2 mm | 0.16 on the faceplate if you want a crisper bezel. |
| Perimeters | 3 (**4** on structural parts) | Marked per part below. |
| Infill | 20% (**40%** on structural parts) | Gyroid or cubic. |
| Top/bottom layers | 4 / 4 | |
| Material | **PETG** | Holds heat-set inserts far better than PLA and will not sag in a warm room. PLA is fine if Rocky lives somewhere cool. |
| Nozzle | 240 °C PETG / 210 °C PLA | |
| Bed | 80 °C PETG / 60 °C PLA | |
| Supports | Off, except `head_back` | |
| Seam | Rear / aligned | Keeps the seam off Rocky's face. |

## The parts

| Part | Orientation | Size (mm) | Volume | Settings |
|---|---|---|---|---|
| `base_shell` | As modelled, floor down | 178 × 174 × 62 | 165 cm³ | 3 perim / 20% |
| `base_deck` | Flat, **race groove up** | 156 × 156 × 11 | 104 cm³ | **4 perim / 40%** — the whole head's weight passes through this plate |
| `turntable` | Flat, **race groove down**, hub up | 150 × 150 × 15 | 99 cm³ | **4 perim / 40%** |
| `yoke` | **Lay it on its back** — rotate 90° about X so the U sits flat | 157 × 108 × 26 | 82 cm³ | **4 perim / 40%** — layers must run across the arms, not along them |
| `head_back` | Rear face down, open side up | 142 × 171 × 57 | 117 cm³ | 3 perim / 20% · **light supports under the brow only** |
| `faceplate` | **Front face down** | 142 × 142 × 10 | 40 cm³ | 3 perim / 25% · the part people look at, so print it well |
| `pod_window` | Outside face down | 46 × 26 × 3 | 3 cm³ | 3 perim / 20% |
| `cable_clip` | Flat, as modelled — **print 4** | 26 × 21 × 7 | 1 cm³ ea | 3 perim / 20% |
| `ball_cage` | Flat | 139 × 139 × 3 | 11 cm³ | 3 perim / 30% — thin, so let it cool |
| `speaker_gasket` | Flat | 54 × 54 × 2 | 2 cm³ | **TPU 95A, 100% infill** — or skip it and use silicone |

Everything fits a 180 × 180 mm bed except `base_shell` (178 × 174, so it *just*
fits) and `yoke` (157 × 108). A 220 mm bed is comfortable.

## Orientation matters in three places

**`yoke` — lay it on its back.** Printed standing up, the layer lines run across
the arms at exactly the plane where the head's weight tries to snap them off.
Lying down, the layers run along the arms and the part is several times
stronger in the direction it is loaded. This is the one orientation mistake that
will actually break your robot.

**`turntable` — race groove down.** The ball race is a 90° V, which is
self-supporting printed either way, but this orientation puts the race on the
build plate where it comes out smoothest, and the ring runs quieter for it.

**`faceplate` — front face down.** The bezel's outer chamfer is the only
overhang, it is 45°, and printing this way puts the visible surface against the
build plate.

## Supports

Only `head_back`, and only under the sensor brow — the part that carries the
camera and microphone above the face. It projects past the head's outer diameter
and its underside is a 45° ramp, which is self-supporting in principle, but the
tip of the ramp benefits from a little help.

In PrusaSlicer or OrcaSlicer, use **support enforcers** or *support on build
plate only* rather than everywhere. Support inside the head shell is a
half-hour of picking plastic out of boss holes for no benefit.

## Heat-set inserts

Nineteen printed bosses take brass inserts. They are worth the small extra
effort — they turn "you get about three assemblies before the threads strip"
into "this will outlast the robot".

1. Fit the insert tip to your iron, set it to **240 °C** for PETG (**220 °C**
   for PLA).
2. Rest the insert on the boss, square.
3. Press slowly, letting the plastic melt rather than forcing it. Two or three
   seconds.
4. Stop flush with the surface. Push in too far and you get a raised ring of
   displaced plastic around the hole; too shallow and the mating part rocks.
5. Let it cool before threading anything into it.

If an insert goes in crooked, heat it back out and try again rather than living
with it — a crooked insert cross-threads the screw and you will find out about
it at final assembly.

## Changing something

The model is parametric, so a dimension change is a rebuild rather than a
redesign:

```bash
cd hardware/cad
$EDITOR rocky_params.scad     # change what you need
./build_all.sh                # re-render everything and validate the meshes
./build_all.sh faceplate      # or just one part
```

The exports are **binary STL** — every slicer reads them, and they are about a
third the size of the ASCII form for the same geometry. Binary STL stores
float32 coordinates, which resolves to well under a micron at the size of these
parts; the printer's own resolution is four orders of magnitude coarser.

`build_all.sh` runs `check_stl.py` over every export and fails the build if any
mesh is not watertight, is non-manifold, has inconsistent winding, or has come
out in more than one piece. Several of those conditions produce a slice that
looks fine and prints wrong, so the check is worth reading rather than skipping.

The three groups of numbers marked **MEASURE** in `rocky_params.scad` are the
ones that depend on which revision of a part you were shipped:

- `disp_*` — the display's glass diameter, carrier size and hole pattern
- `sv_*` — the pan servo's body and mounting dimensions
- `msv_*` — the tilt servo's

Put calipers on yours before printing. Two minutes there against an afternoon of
reprinting a faceplate that does not fit.

## Checking your prints

Before assembly:

- **Ball race:** drop a 6 mm ball into the groove on both `base_deck` and
  `turntable`. It should sit in the V and roll freely, not bind and not rattle.
- **Heat-set bosses:** thread a screw into each one by hand. All nineteen.
- **Yoke:** hold it by the crossbar and flex the arms gently. They should feel
  stiff. If an arm flexes visibly, it was printed in the wrong orientation.
- **Faceplate:** offer the display up to the pocket. It should drop in with a
  little clearance. If it fouls, correct `disp_glass_d` rather than filing.

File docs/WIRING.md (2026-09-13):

# Wiring

Every connection in Rocky, and the handful of config lines that make the Pi
recognise the hardware.

<!-- wiring:interconnect -->
interconnect diagram
<!-- /wiring -->

The three diagrams and every table in this document are generated from one
description of the electrics — see [hardware/README.md](../hardware/README.md).

Work through this with the robot **unpowered and unassembled**. Getting the
electronics working on the bench, with `rocky check` reporting everything real,
is far easier than debugging it inside a closed head.

---

## Power

<!-- wiring:power -->
power diagram
<!-- /wiring -->

One 12 V input feeds two regulators. The Pi and the servos never share a rail,
which is what stops a servo stalling from browning out the Pi mid-sentence.

```
  12V 5A PSU
      │
      ├── [ 3A fuse ] ── [ latching switch ] ──┬── Buck A  5.1V 5A ──► Pi 5 (USB-C)
      │                                        │
      │                                        └── Buck B  6.0V 3A ──► PCA9685 V+
      │                                                                  │
      └── GND ─────────────────────── common ground ────────────────────┘
                                           │
                              470µF across the servo rail
```

**Set both regulators before connecting anything.** Wire the 12 V in, switch on,
and put a meter on each output. Adjustable modules ship at arbitrary settings
and a module set to 12 V will destroy a Pi instantly.

- Buck A must read **5.05–5.15 V**. Not 5.00 — the drop along the USB-C cable at
  4 A is real and the Pi 5 is unusually fussy about it.
- Buck B must read **5.9–6.1 V**. Above 6.2 V will cook a hobby servo.

Ground everything to one point. A star ground at the 12 V jack is easiest.
The Pi's ground and the servo ground **must** be connected or the PWM signal has
no reference and the servos will twitch continuously.

---

## GPIO header

<!-- wiring:gpio -->
gpio diagram
<!-- /wiring -->

Nine pins are used: four to the Qwiic SHIM, five to the amplifier. The SHIM
sits over the first few and the rest are wired directly — which is exactly why
the design uses a SHIM rather than a HAT for I²C, since a HAT would cover the
header the amplifier needs.

<!-- tables:gpio -->
| Pin | Signal | Goes to |
|-----|---|---|
| 1 | 3V3 | Qwiic SHIM |
| 3 | GPIO2 / SDA1 | Qwiic SHIM |
| 4 | 5V | amplifier Vin |
| 5 | GPIO3 / SCL1 | Qwiic SHIM |
| 6 | GND | amplifier GND |
| 9 | GND | Qwiic SHIM |
| 12 | GPIO18 / PCM_CLK | amplifier BCLK |
| 35 | GPIO19 / PCM_FS | amplifier LRC |
| 40 | GPIO21 / PCM_DOUT | amplifier DIN |
<!-- /tables -->

Leave the amplifier's **GAIN** and **SD** pins unconnected. Floating gives 9 dB
and mono `(L+R)/2`, which is what you want from a single speaker.

### Amplifier to speaker

The amplifier is in the **head**; the speaker is in the **base**. These two
conductors are part of the pan-joint harness.

| MAX98357A | Speaker |
|---|---|
| `+` | speaker `+` |
| `-` | speaker `-` |

Do not go by wire colour. Adafruit's 3968 shipped red/black leads until its
January 2024 revision and does not any more, and generic 40 mm drivers are
inconsistent about it. Find the terminal marked `+` on the frame, or touch a
1.5 V cell across the terminals and watch which way the cone moves — out is
positive.

Not polarity critical with one driver, but stay consistent so a future second
speaker is in phase.

Putting the amplifier in the head is deliberate. With it beside the speaker,
BCLK, LRC, DIN and its supply — five conductors, one of them a 3 MHz clock —
would all have to cross a joint that flexes every time Rocky turns. Analogue
speaker output over the same joint is a far easier life.

---

## I²C

| Device | Address | Notes |
|---|---|---|
| PCA9685 | `0x40` | Default, all address jumpers open. |
| *(display touch controller)* | varies | Present if your panel has touch; harmless. |

Qwiic SHIM → PCA9685, four conductors:

| Qwiic | Colour | PCA9685 |
|---|---|---|
| GND | black | GND |
| 3V3 | red | VCC *(logic — **not** V+)* |
| SDA | blue | SDA |
| SCL | yellow | SCL |

> **VCC and V+ are different pins and confusing them is the classic mistake.**
> VCC is 3.3 V logic from the Pi. V+ is the 6 V servo rail, which goes to the
> green screw terminal. Putting 6 V into VCC pushes 6 V onto the Pi's I²C bus.

### Servo rail

| From | To |
|---|-----|
| Buck B `+` (6 V) | PCA9685 screw terminal `+` |
| Buck B `−` | PCA9685 screw terminal `−` |
| 470 µF `+` | screw terminal `+` |
| 470 µF `−` | screw terminal `−` |

Mind the capacitor's polarity. Backwards, it will vent.

### Servos

| Servo | Channel | Wire colours |
|---|---|---|
| Pan | `0` | brown/black → GND · red → V+ · orange/yellow → signal |
| Tilt | `1` | same |

These match `motion.pan.channel` and `motion.tilt.channel`.

---

## Ribbon cables

Both are Pi 5 specific: 22-pin 0.5 mm at the Pi end, 15-pin 1 mm at the device.
**They are not interchangeable** — a camera cable in a display socket will not
work and can damage the panel.

| Cable | Pi 5 connector | Other end |
|---|---|---|
| Camera | `CAM/DISP 0` | Camera Module 3 |
| Display | `CAM/DISP 1` | Display carrier |

Contacts face the correct way when the blue stiffener is away from the board on
the Pi end. Seat fully, then press the latch down evenly. A ribbon that is
nearly seated produces a display that flickers or a camera that enumerates and
returns nothing — both of which look like software faults and are not.

---

## The pan-joint harness

Eleven conductors cross the rotating joint, between the base and the head:

<!-- tables:harness -->
| Conductor | Gauge | Purpose |
|---|---|---|
| 5.1V | 20 AWG | Pi supply |
| GND | 20 AWG | Pi supply return |
| GND | 20 AWG | signal ground |
| SDA | 26 AWG | I2C to the servo driver |
| SCL | 26 AWG | I2C to the servo driver |
| 3V3 | 26 AWG | I2C logic level |
| Tilt signal | 26 AWG | PWM to the tilt servo |
| Tilt V+ | 26 AWG | 6V to the tilt servo |
| Tilt GND | 26 AWG | tilt servo return |
| Speaker + | 22 AWG | amplifier output, head to base |
| Speaker - | 22 AWG | amplifier output return |
<!-- /tables -->

**Use silicone-insulated wire.** This bundle flexes every time Rocky turns —
thousands of cycles a week. PVC hookup wire work-hardens and eventually cracks
inside the insulation, which produces an intermittent fault that is genuinely
horrible to find.

Twist the bundle loosely, pass it through the turntable's 16 mm bore at 30 mm
radius, and leave a **generous service loop** — around 60 mm of slack coiled in
the base. Rotate the head fully both ways by hand before closing anything up and
watch that the bundle coils and uncoils rather than pulling taut or snagging.
The printed stop post limits pan to ±100° so the harness can never be wrung, but
it will not save a harness that was too short to begin with.

---

## Every connection

The complete list, generated from the same data as the diagrams above.

<!-- tables:connections -->
| From | To | Carries | Wire | Note |
|---|-----|---|---|---|
| 12V 5A supply | 3A fuse | 12V | 18 AWG | — |
| 3A fuse | power switch | 12V | 18 AWG | — |
| power switch | 5.1V 5A regulator | 12V | 18 AWG | — |
| power switch | 6.0V 3A regulator | 12V | 18 AWG | — |
| 5.1V 5A regulator | Raspberry Pi 5 | 5.1V to USB-C | 20 AWG | crosses the pan joint |
| 6.0V 3A regulator | PCA9685 servo driver | 6.0V to V+ | 20 AWG | — |
| 6.0V 3A regulator | 470uF capacitor | across V+ | — | — |
| Raspberry Pi 5 | Qwiic SHIM | GPIO2 / SDA | — | — |
| Qwiic SHIM | PCA9685 servo driver | SDA | 26 AWG | crosses the pan joint |
| Qwiic SHIM | PCA9685 servo driver | SCL | 26 AWG | crosses the pan joint |
| Qwiic SHIM | PCA9685 servo driver | 3V3 logic | 26 AWG | crosses the pan joint |
| Raspberry Pi 5 | MAX98357A amplifier | I2S: BCLK, LRC, DIN | 26 AWG | — |
| Raspberry Pi 5 | MAX98357A amplifier | 5V + GND | 26 AWG | — |
| MAX98357A amplifier | 40mm speaker | 4 ohm, 3W | 22 AWG | crosses the pan joint |
| PCA9685 servo driver | pan servo | channel 0 | — | — |
| PCA9685 servo driver | tilt servo | channel 1 | 26 AWG | crosses the pan joint |
| Raspberry Pi 5 | round display | DSI, 22 to 15 pin | — | CAM/DISP 1 |
| Raspberry Pi 5 | Camera Module 3 | CSI, 22 to 15 pin | — | CAM/DISP 0 |
| Raspberry Pi 5 | USB microphone | USB | — | — |
<!-- /tables -->

---

## Pi configuration

Add to `/boot/firmware/config.txt`:

```ini
# --- I2C for the servo driver -------------------------------------------
dtparam=i2c_arm=on
dtparam=i2c_arm_baudrate=400000

# --- I2S audio out ------------------------------------------------------
# Turn off the default (HDMI) audio first, or the I2S device is not created.
dtparam=audio=off
dtoverlay=hifiberry-dac
# Newer kernels have a dedicated overlay; use it instead if present:
#dtoverlay=max98357a,no-sdmode

# --- camera -------------------------------------------------------------
camera_auto_detect=1

# --- display ------------------------------------------------------------
dtoverlay=vc4-kms-v3d
# For the Waveshare 4in round DSI panel. Check their wiki for the exact
# overlay name your panel revision wants - this is the line most likely to
# need adjusting for your hardware.
dtoverlay=vc4-kms-dsi-waveshare-panel,4_0_inch

# --- power --------------------------------------------------------------
# Asserts that the supply really can deliver 5A, so the Pi 5 stops limiting
# USB current and complaining about it. Only set this if your Buck A genuinely
# can - the USB microphone depends on it.
usb_max_current_enable=1
```

Reboot, then check each one:

```bash
i2cdetect -y 1          # expect 40
aplay -l                # expect a card with "sndrpihifiberry" or similar
arecord -l              # expect your USB microphone
rpicam-hello --list-cameras
```

`rocky check` reports all four at once and tells you which backends are real
and which have silently fallen back to simulation.

---

## Before the first power-up

1. Meter both regulator outputs, unloaded. **5.1 V and 6.0 V.**
2. Check continuity between the Pi's ground and the servo ground.
3. Confirm the servo rail is **not** connected to the PCA9685's VCC pin.
4. Check the 470 µF capacitor's polarity.
5. Power up with the servos **unplugged**. Confirm the Pi boots and
   `i2cdetect` finds `0x40`.
6. Plug in one servo. Run `rocky calibrate pan`. It should move smoothly and
   quietly. If it buzzes at rest, that is normal for a digital servo — it is
   exactly what `motion.idle_torque_off_s` exists to stop.
7. Plug in the second servo and repeat with `rocky calibrate tilt`.

If a servo slams to one end and stays there, stop and switch off. It is almost
always a signal wire on the wrong channel or a missing common ground.

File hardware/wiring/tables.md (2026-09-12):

<!-- Generated by hardware/wiring/generate.py. Do not edit by hand. -->

### Every connection

| From | To | Carries | Wire | Note |
|---|-----|---|---|---|
| 12V 5A supply | 3A fuse | 12V | 18 AWG | — |
| 3A fuse | power switch | 12V | 18 AWG | — |
| power switch | 5.1V 5A regulator | 12V | 18 AWG | — |
| power switch | 6.0V 3A regulator | 12V | 18 AWG | — |
| 5.1V 5A regulator | Raspberry Pi 5 | 5.1V to USB-C | 20 AWG | crosses the pan joint |
| 6.0V 3A regulator | PCA9685 servo driver | 6.0V to V+ | 20 AWG | — |
| 6.0V 3A regulator | 470uF capacitor | across V+ | — | — |
| Raspberry Pi 5 | Qwiic SHIM | GPIO2 / SDA | — | — |
| Qwiic SHIM | PCA9685 servo driver | SDA | 26 AWG | crosses the pan joint |
| Qwiic SHIM | PCA9685 servo driver | SCL | 26 AWG | crosses the pan joint |
| Qwiic SHIM | PCA9685 servo driver | 3V3 logic | 26 AWG | crosses the pan joint |
| Raspberry Pi 5 | MAX98357A amplifier | I2S: BCLK, LRC, DIN | 26 AWG | — |
| Raspberry Pi 5 | MAX98357A amplifier | 5V + GND | 26 AWG | — |
| MAX98357A amplifier | 40mm speaker | 4 ohm, 3W | 22 AWG | crosses the pan joint |
| PCA9685 servo driver | pan servo | channel 0 | — | — |
| PCA9685 servo driver | tilt servo | channel 1 | 26 AWG | crosses the pan joint |
| Raspberry Pi 5 | round display | DSI, 22 to 15 pin | — | CAM/DISP 1 |
| Raspberry Pi 5 | Camera Module 3 | CSI, 22 to 15 pin | — | CAM/DISP 0 |
| Raspberry Pi 5 | USB microphone | USB | — | — |

### The pan-joint harness (11 conductors)

| Conductor | Gauge | Purpose |
|---|---|---|
| 5.1V | 20 AWG | Pi supply |
| GND | 20 AWG | Pi supply return |
| GND | 20 AWG | signal ground |
| SDA | 26 AWG | I2C to the servo driver |
| SCL | 26 AWG | I2C to the servo driver |
| 3V3 | 26 AWG | I2C logic level |
| Tilt signal | 26 AWG | PWM to the tilt servo |
| Tilt V+ | 26 AWG | 6V to the tilt servo |
| Tilt GND | 26 AWG | tilt servo return |
| Speaker + | 22 AWG | amplifier output, head to base |
| Speaker - | 22 AWG | amplifier output return |

### GPIO pins in use (9 of 40)

| Pin | Signal | Goes to |
|-----|---|---|
| 1 | 3V3 | Qwiic SHIM |
| 3 | GPIO2 / SDA1 | Qwiic SHIM |
| 4 | 5V | amplifier Vin |
| 5 | GPIO3 / SCL1 | Qwiic SHIM |
| 6 | GND | amplifier GND |
| 9 | GND | Qwiic SHIM |
| 12 | GPIO18 / PCM_CLK | amplifier BCLK |
| 35 | GPIO19 / PCM_FS | amplifier LRC |
| 40 | GPIO21 / PCM_DOUT | amplifier DIN |

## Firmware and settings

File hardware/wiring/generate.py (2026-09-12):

#!/usr/bin/env python3
"""Draw Rocky's wiring diagrams, and the tables that go with them.

Everything comes from wiring_data.py, so the pictures and the tables in
docs/WIRING.md cannot disagree. Run it after changing anything electrical:

    python3 generate.py

Writes SVGs to hardware/img/ and markdown fragments to hardware/wiring/.
No third-party dependencies - the SVG is written by hand, which for diagrams
this regular is less code than configuring a library would be.
"""

from __future__ import annotations

import html
import sys
from pathlib import Path

sys.path.insert(0, str(Path(__file__).parent))

import wiring_data as W  # noqa: E402

OUT_IMG = Path(__file__).resolve().parents[1] / "img"
OUT_DOC = Path(__file__).resolve().parent

FONT = "ui-sans-serif, -apple-system, 'Segoe UI', Roboto, Helvetica, Arial, sans-serif"
MONO = "ui-monospace, 'SF Mono', Menlo, Consolas, monospace"


# ---------------------------------------------------------------------------
# a very small SVG writer
# ---------------------------------------------------------------------------


class Svg:
    """Enough SVG to draw a wiring diagram and nothing more.

    Output is self-contained and carries its own light background: these get
    embedded as images (where `currentColor` would resolve to black on a dark
    page) and they get printed and pinned up next to the bench.
    """

    def __init__(self, width: int, height: int, title: str, desc: str) -> None:
        self.w, self.h = width, height
        self.title, self.desc = title, desc
        self.body: list[str] = []

    # -- primitives --------------------------------------------------------

    def rect(self, x, y, w, h, fill=W.PAPER, stroke=W.RULE, rx=6, sw=1.5, dash=None):
        d = f' stroke-dasharray="{dash}"' if dash else ""
        self.body.append(
            f'<rect x="{x}" y="{y}" width="{w}" height="{h}" rx="{rx}" '
            f'fill="{fill}" stroke="{stroke}" stroke-width="{sw}"{d}/>'
        )

    def line(self, x1, y1, x2, y2, stroke=W.RULE, sw=1.5, dash=None, cap="round"):
        d = f' stroke-dasharray="{dash}"' if dash else ""
        self.body.append(
            f'<line x1="{x1}" y1="{y1}" x2="{x2}" y2="{y2}" stroke="{stroke}" '
            f'stroke-width="{sw}" stroke-linecap="{cap}"{d}/>'
        )

    def path(self, points, stroke, sw=3.0, dash=None, arrow=False):
        d = " ".join(f"{'M' if i == 0 else 'L'} {x} {y}" for i, (x, y) in enumerate(points))
        da = f' stroke-dasharray="{dash}"' if dash else ""
        mk = ' marker-end="url(#tip)"' if arrow else ""
        self.body.append(
            f'<path d="{d}" fill="none" stroke="{stroke}" stroke-width="{sw}" '
            f'stroke-linejoin="round" stroke-linecap="round"{da}{mk}/>'
        )

    def text(self, x, y, s, size=13, anchor="start", fill=W.INK, weight="500",
             font=FONT, opacity=1.0):
        self.body.append(
            f'<text x="{x}" y="{y}" font-family="{font}" font-size="{size}" '
            f'font-weight="{weight}" fill="{fill}" text-anchor="{anchor}" '
            f'opacity="{opacity}">{html.escape(s)}</text>'
        )

    def dot(self, x, y, r=4, fill=W.INK):
        self.body.append(f'<circle cx="{x}" cy="{y}" r="{r}" fill="{fill}"/>')

    # -- composites --------------------------------------------------------

    def block(self, x, y, w, h, name, sub="", accent=W.ACCENT):
        """A component box with a coloured spine on its left edge."""
        self.rect(x, y, w, h, fill=W.PANEL, stroke=W.RULE, rx=8)
        self.body.append(
            f'<path d="M {x} {y+8} L {x} {y+h-8}" stroke="{accent}" '
            f'stroke-width="4" stroke-linecap="round"/>'
        )
        ty = y + h / 2 + (0 if not sub else -6)
        self.text(x + 14, ty + 5, name, 14, weight="650")
        if sub:
            self.text(x + 14, ty + 22, sub, 11.5, fill=W.INK_SOFT, weight="400")

    def wire(self, points, net, label="", label_at=0.5, side="above", sw=3.4):
        """A run of wire, drawn in its real insulation colour."""
        colour = W.WIRE[net]
        self.path(points, colour, sw=sw)
        if label:
            i = max(0, min(len(points) - 2, int((len(points) - 1) * label_at)))
            (x1, y1), (x2, y2) = points[i], points[i + 1]
            mx, my = (x1 + x2) / 2, (y1 + y2) / 2
            dy = -9 if side == "above" else 17
            anchor = "middle"
            if x1 == x2:                       # vertical run: label beside it
                mx, my, dy, anchor = x1 + 9, (y1 + y2) / 2, 4, "start"
            self.text(mx, my + dy, label, 11.5, anchor=anchor, fill=W.INK_SOFT,
                      weight="500", font=MONO)

    def legend(self, x, y, entries, columns=1, gap=22, swatch=26):
        for i, (net, label) in enumerate(entries):
            col, row = i % columns, i // columns
            cx = x + col * 240
            cy = y + row * gap
            self.line(cx, cy, cx + swatch, cy, stroke=W.WIRE[net], sw=4)
            self.text(cx + swatch + 10, cy + 4, label, 11.5, fill=W.INK_SOFT, weight="500")

    # -- output ------------------------------------------------------------

    def render(self) -> str:
        return (
            f'<svg xmlns="http://www.w3.org/2000/svg" viewBox="0 0 {self.w} {self.h}" '
            f'width="{self.w}" height="{self.h}" role="img" '
            f'aria-label="{html.escape(self.desc)}">\n'
            f"  <title>{html.escape(self.title)}</title>\n"
            f"  <desc>{html.escape(self.desc)}</desc>\n"
            '  <defs><marker id="tip" viewBox="0 0 10 10" refX="9" refY="5" '
            'markerWidth="6" markerHeight="6" orient="auto-start-reverse">'
            f'<path d="M 0 0 L 10 5 L 0 10 z" fill="{W.INK}"/></marker></defs>\n'
            f'  <rect width="{self.w}" height="{self.h}" fill="{W.PAPER}"/>\n  '
            + "\n  ".join(self.body)
            + "\n</svg>\n"
        )

    def save(self, path: Path) -> Path:
        path.write_text(self.render())
        return path


# ---------------------------------------------------------------------------
# 1. the power tree
# ---------------------------------------------------------------------------


def diagram_power() -> Svg:
    s = Svg(1270, 610, "Rocky power distribution",
            "One 12V supply feeds a fuse and switch, then splits into a 5.1V "
            "regulator for the Raspberry Pi and a 6.0V regulator for the servo "
            "rail, with a common ground.")

    s.text(40, 44, "Power distribution", 21, weight="700")
    s.text(40, 68, "One cable to the desk. Everything else is made inside Rocky.",
           13, fill=W.INK_SOFT, weight="400")

    y_hi, y_lo = 150, 268
    s.block(40, y_hi - 30, 150, 60, "12V 5A supply", "2.1mm barrel", W.WIRE["12v"])
    s.block(250, y_hi - 26, 96, 52, "3A fuse", "", W.WIRE["12v"])
    s.block(400, y_hi - 26, 118, 52, "switch", "", W.WIRE["12v"])

    s.wire([(190, y_hi), (250, y_hi)], "12v")
    s.wire([(346, y_hi), (400, y_hi)], "12v")
    s.wire([(518, y_hi), (570, y_hi)], "12v", "12V", side="above")

    # the split: one branch stays high for the Pi, one drops for the servos
    s.dot(570, y_hi, 5, W.WIRE["12v"])
    s.wire([(570, y_hi), (570, y_lo), (630, y_lo)], "12v")
    s.wire([(570, y_hi), (630, y_hi)], "12v")

    # --- 5.1V branch, feeding the head -----------------------------------
    s.block(630, y_hi - 34, 190, 68, "5.1V regulator", "5A, set it before wiring",
            W.WIRE["5v"])
    s.wire([(820, y_hi), (900, y_hi)], "5v", "5.1V", side="above")
    s.block(900, y_hi - 34, 170, 68, "Raspberry Pi 5", "via USB-C", W.WIRE["5v"])

    # --- 6.0V branch, feeding the servo rail -----------------------------
    s.block(630, y_lo - 34, 190, 68, "6.0V regulator", "3A, set it before wiring",
            W.WIRE["6v"])
    s.wire([(820, y_lo), (900, y_lo)], "6v", "6.0V", side="above")
    s.block(900, y_lo - 34, 170, 68, "PCA9685 V+", "servo rail", W.WIRE["6v"])

    # smoothing capacitor, hung off the rail to the right of the driver
    cap_x = 1128
    s.wire([(1070, y_lo), (cap_x, y_lo), (cap_x, 330)], "6v", sw=3.0)
    s.line(cap_x - 26, 330, cap_x + 26, 330, W.INK, 3)
    s.line(cap_x - 26, 342, cap_x + 26, 342, W.INK, 3)
    s.text(cap_x + 34, 372, "470uF", 11.5, fill=W.INK_SOFT, font=MONO)
    s.text(cap_x + 34, 388, "polarity!", 10.5, fill=W.INK_SOFT, font=MONO)
    s.wire([(cap_x, 342), (cap_x, 470)], "gnd", sw=3.0)

    # --- servos hang off the driver's channels ---------------------------
    # Both servos sit above the ground rail; a block straddling it reads as
    # a short circuit even though it is only a drawing.
    s.block(900, 340, 170, 44, "pan servo", "", W.WIRE["signal"])
    s.block(900, 398, 170, 44, "tilt servo", "", W.WIRE["signal"])
    s.wire([(880, y_lo + 34), (880, 362), (900, 362)], "signal", sw=2.6)
    s.wire([(858, y_lo + 34), (858, 420), (900, 420)], "signal", sw=2.6)
    s.text(892, 336, "ch 0", 11, anchor="end", fill=W.INK_SOFT, font=MONO)
    s.text(892, 394, "ch 1", 11, anchor="end", fill=W.INK_SOFT, font=MONO)

    # --- common ground ----------------------------------------------------
    gy = 470
    s.line(40, gy, 1230, gy, W.WIRE["gnd"], 3.5)
    s.text(40, gy + 26, "Common ground", 13, weight="650")
    s.text(40, gy + 44,
           "The Pi's ground and the servo ground must be joined, or the PWM",
           12, fill=W.INK_SOFT, weight="400")
    s.text(40, gy + 62,
           "signal has no reference and the servos twitch continuously.",
           12, fill=W.INK_SOFT, weight="400")
    for x in (115, 480, 725, cap_x):
        s.dot(x, gy, 5, W.WIRE["gnd"])
    s.wire([(115, 180), (115, gy)], "gnd", sw=3.0)
    s.wire([(480, 176), (480, gy)], "gnd", sw=3.0)
    s.wire([(725, 302), (725, gy)], "gnd", sw=3.0)

    # --- the warning that matters ----------------------------------------
    s.rect(640, 528, 590, 62, fill="#fff7ed", stroke="#fdba74", rx=8)
    s.text(660, 552, "Set both regulator outputs before connecting anything", 12.5,
           weight="650", fill="#9a3412")
    s.text(660, 574, "5.05-5.15V and 5.9-6.1V. A module left set to 12V kills a Pi instantly.",
           11.5, weight="400", fill="#9a3412")

    s.legend(40, 552, [("12v", "12V input"), ("5v", "5.1V, Pi"),
                       ("6v", "6.0V, servos"), ("gnd", "ground")], columns=2)
    return s


# ---------------------------------------------------------------------------
# 2. the GPIO header
# ---------------------------------------------------------------------------


def diagram_gpio() -> Svg:
    rows = 20
    pitch = 34
    top = 150
    cx = 540                       # centre line of the header
    pin_w, pin_h = 74, 24

    s = Svg(1080, top + rows * pitch + 150, "Raspberry Pi 5 GPIO header",
            "The forty-pin header with the nine pins Rocky uses highlighted: "
            "four to the Qwiic SHIM and five to the I2S amplifier.")

    s.text(40, 44, "GPIO header", 21, weight="700")
    s.text(40, 68,
           "Nine pins used. Everything else stays free, which is why Rocky uses "
           "a Qwiic SHIM rather than a HAT.", 13, fill=W.INK_SOFT, weight="400")

    s.text(cx - pin_w - 10, top - 26, "odd", 11.5, anchor="end",
           fill=W.INK_SOFT, font=MONO)
    s.text(cx + pin_w + 10, top - 26, "even", 11.5, fill=W.INK_SOFT, font=MONO)
    s.rect(cx - pin_w - 14, top - 16, (pin_w + 14) * 2, rows * pitch + 4,
           fill="#eef2f7", stroke=W.RULE, rx=10)

    for row in range(rows):
        y = top + row * pitch
        for side in (-1, 1):
            pin = W.GPIO_HEADER[row * 2 + (0 if side < 0 else 1)]
            x = cx - pin_w if side < 0 else cx
            used = bool(pin.use)
            colour = W.WIRE.get(pin.net, W.RULE) if used else W.RULE
            s.rect(x + (2 if side < 0 else 0), y, pin_w - 2, pin_h,
                   fill=colour if used else "#ffffff",
                   stroke=colour if used else "#dbe2ec", rx=5, sw=1.4)
            s.text(x + pin_w / 2, y + 17, str(pin.number), 12.5,
                   anchor="middle", weight="700",
                   fill="#ffffff" if used else W.INK_SOFT)

            # the name, just outside the header body
            nx = cx - pin_w - 24 if side < 0 else cx + pin_w + 24
            s.text(nx, y + 17, pin.name, 12, anchor="end" if side < 0 else "start",
                   fill=W.INK if used else "#9aa7b8",
                   weight="600" if used else "400", font=MONO)

            if used:
                # Leader out to whatever the pin connects to. It has to start
                # clear of the pin name or it draws a line through the text;
                # the name is monospaced, so its width is predictable.
                name_w = len(pin.name) * 7.25
                lx = 250 if side < 0 else 836
                if side < 0:
                    s.line(nx - name_w - 14, y + 12, lx, y + 12, colour, 2.0)
                    s.text(lx - 12, y + 16, pin.use, 12, anchor="end",
                           weight="600", fill=colour)
                else:
                    s.line(nx + name_w + 14, y + 12, lx, y + 12, colour, 2.0)
                    s.text(lx + 12, y + 16, pin.use, 12, weight="600", fill=colour)

    bottom = top + rows * pitch + 40
    s.legend(40, bottom, [("3v3", "3V3 logic"), ("5v", "5V"),
                          ("gnd", "ground"), ("i2c_sda", "I2C SDA / I2S clocks"),
                          ("i2c_scl", "I2C SCL")], columns=2)
    s.text(600, bottom - 2, "Pin 1 is the corner nearest the microSD slot.",
           12, fill=W.INK_SOFT, weight="400")
    s.text(600, bottom + 20,
           "Leave the amplifier's GAIN and SD pins unconnected: floating gives",
           12, fill=W.INK_SOFT, weight="400")
    s.text(600, bottom + 38,
           "9dB and mono (L+R)/2, which is what one speaker wants.",
           12, fill=W.INK_SOFT, weight="400")
    return s


# ---------------------------------------------------------------------------
# 3. what connects to what, and what crosses the rotating joint
# ---------------------------------------------------------------------------


def diagram_interconnect() -> Svg:
    """Every board and every wire, split by which half of the robot it is in.

    The layout is arranged so no run passes through a block: the two halves
    each keep clear vertical channels at x = 90 and x = 1150/1190, and the I2C
    trio drops through the gap between the left column and the Pi.
    """
    s = Svg(1260, 900, "Rocky interconnect",
            "Every board in Rocky and the wires between them, split into the "
            "head and the base, with the eleven-conductor harness that crosses "
            "the rotating pan joint.")

    s.text(40, 44, "What connects to what", 21, weight="700")
    s.text(40, 68,
           "The head turns. Every wire between the two halves has to survive "
           "that, thousands of times a week.", 13, fill=W.INK_SOFT, weight="400")

    # --- the two halves ---------------------------------------------------
    s.rect(40, 100, 1180, 296, fill="#f7f9fc", stroke=W.RULE, rx=12)
    s.text(60, 126, "HEAD", 12, fill=W.INK_SOFT, weight="700")
    s.text(60, 144, "turns with the pan servo", 11, fill=W.INK_SOFT, weight="400")

    s.rect(40, 560, 1180, 290, fill="#f7f9fc", stroke=W.RULE, rx=12)
    s.text(60, 586, "BASE", 12, fill=W.INK_SOFT, weight="700")
    s.text(60, 604, "fixed to the desk", 11, fill=W.INK_SOFT, weight="400")

    # --- head -------------------------------------------------------------
    s.block(150, 166, 190, 58, "round display", "DSI ribbon", W.WIRE["data"])
    s.block(150, 252, 190, 58, "Camera Module 3", "CSI ribbon", W.WIRE["data"])
    s.block(150, 330, 190, 52, "USB microphone", "", W.WIRE["data"])
    s.block(480, 196, 220, 96, "Raspberry Pi 5", "the only computer", W.ACCENT)
    s.block(850, 166, 200, 58, "MAX98357A amp", "I2S in, 3W out", W.WIRE["signal"])
    s.block(850, 252, 200, 58, "Qwiic SHIM", "I2C off the header", W.WIRE["i2c_sda"])
    s.block(850, 330, 200, 52, "tilt servo", "channel 1", W.WIRE["signal"])

    # --- base -------------------------------------------------------------
    s.block(150, 640, 190, 58, "pan servo", "channel 0", W.WIRE["signal"])
    s.block(480, 620, 220, 96, "PCA9685", "16 channels, 2 used", W.ACCENT)
    s.block(850, 640, 200, 58, "40mm speaker", "fires down", W.WIRE["audio"])
    s.block(150, 752, 190, 52, "5.1V regulator", "feeds the Pi", W.WIRE["5v"])
    s.block(480, 752, 220, 52, "6.0V regulator", "feeds the servos", W.WIRE["6v"])

    # --- inside the head ---------------------------------------------------
    s.wire([(340, 195), (410, 195), (410, 228), (480, 228)], "data", "DSI", sw=2.6)
    s.wire([(340, 281), (410, 281), (410, 260), (480, 260)], "data", "CSI", sw=2.6)
    s.wire([(340, 356), (440, 356), (440, 284), (480, 284)], "data", "USB", sw=2.6)
    s.wire([(700, 216), (780, 216), (780, 195), (850, 195)], "signal",
           "I2S + 5V", sw=2.6)
    s.wire([(700, 260), (790, 260), (790, 281), (850, 281)], "i2c_sda", "I2C", sw=2.6)

    # --- inside the base ---------------------------------------------------
    s.wire([(480, 660), (340, 660)], "signal", "ch 0", sw=2.6)
    s.wire([(590, 752), (590, 716)], "6v", "V+", sw=2.6)

    # --- the joint ---------------------------------------------------------
    jy = 478
    s.line(40, jy, 1220, jy, W.INK_SOFT, 2.0, dash="10 7")
    s.rect(420, jy - 26, 420, 52, fill="#fff7ed", stroke="#fdba74", rx=9)
    s.text(630, jy - 5, "THE ROTATING PAN JOINT", 12.5, anchor="middle",
           weight="700", fill="#9a3412")
    s.text(630, jy + 14, "11 conductors cross here, all in silicone wire",
           11.5, anchor="middle", weight="400", fill="#9a3412")

    # --- the six runs that cross -------------------------------------------
    # No inline label on the crossings; the caption under the joint names them.
    s.wire([(480, 240), (90, 240), (90, 778), (150, 778)], "5v", sw=3.2)
    for x, net in ((355, "i2c_sda"), (382, "i2c_scl"), (409, "3v3")):
        s.wire([(850, 300), (x, 300), (x, 600), (460, 600), (460, 646), (480, 646)],
               net, sw=2.4)
    s.wire([(1050, 356), (1150, 356), (1150, 730), (720, 730), (720, 700), (700, 700)],
           "signal", sw=3.2)
    s.wire([(1050, 195), (1190, 195), (1190, 669), (1050, 669)], "audio", sw=3.2)

    # Captions for the crossings. The two on the right are stacked because
    # their channels are only 40px apart and the text is wider than that.
    for x, dy, caption in ((90, 46, "5.1V + GND"), (382, 46, "SDA / SCL / 3V3"),
                           (1088, 46, "tilt x3"), (1088, 64, "speaker +/-")):
        s.text(x, jy + dy, caption, 10.5, anchor="middle", fill=W.INK_SOFT,
               weight="600", font=MONO)

    s.legend(40, 872, [("data", "ribbon and USB"), ("signal", "I2S and PWM"),
                       ("i2c_sda", "I2C"), ("audio", "speaker"),
                       ("5v", "5.1V"), ("6v", "6.0V")], columns=3)
    return s


# ---------------------------------------------------------------------------
# markdown fragments, so the tables cannot drift from the pictures
# ---------------------------------------------------------------------------


def markdown_tables() -> str:
    where = {d.key: d for d in W.DEVICES}
    lines = ["<!-- Generated by hardware/wiring/generate.py. Do not edit by hand. -->", ""]

    lines += ["### Every connection", "",
              "| From | To | Carries | Wire | Note |",
              "|------|-----|---------|------|------|"]
    for link in W.LINKS:
        lines.append(
            f"| {where[link.frm].name} | {where[link.to].name} | "
            f"{link.label or link.net} | {link.gauge or '—'} | {link.note or '—'} |"
        )

    lines += ["", f"### The pan-joint harness ({len(W.HARNESS)} conductors)", "",
              "| Conductor | Gauge | Purpose |", "|-----------|-------|---------|"]
    for name, gauge, purpose in W.HARNESS:
        lines.append(f"| {name} | {gauge} | {purpose} |")

    used = [p for p in W.GPIO_HEADER if p.use]
    lines += ["", f"### GPIO pins in use ({len(used)} of 40)", "",
              "| Pin | Signal | Goes to |", "|-----|--------|---------|"]
    for pin in used:
        lines.append(f"| {pin.number} | {pin.name} | {pin.use} |")

    return "\n".join(lines) + "\n"


def main() -> int:
    problems = W.validate()
    if problems:
        print("wiring data is inconsistent:")
        for p in problems:
            print(f"  - {p}")
        return 1

    OUT_IMG.mkdir(parents=True, exist_ok=True)
    for name, fn in (("power", diagram_power), ("gpio", diagram_gpio),
                     ("interconnect", diagram_interconnect)):
        path = fn().save(OUT_IMG / f"wiring-{name}.svg")
        print(f"  {path.name}  {path.stat().st_size:,} bytes")

    doc = OUT_DOC / "tables.md"
    doc.write_text(markdown_tables())
    print(f"  {doc.name}  {doc.stat().st_size:,} bytes")
    return 0


if __name__ == "__main__":
    raise SystemExit(main())

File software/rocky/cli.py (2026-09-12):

"""Command line entry points."""

from __future__ import annotations

import argparse
import asyncio
import contextlib
import json
import logging
import signal
import sys
from typing import Any

from rocky import __version__
from rocky.config import Config

log = logging.getLogger("rocky.cli")


def main(argv: list[str] | None = None) -> int:
    parser = argparse.ArgumentParser(
        prog="rocky", description="Rocky - a compact desk companion"
    )
    parser.add_argument("--config", help="path to config.toml")
    parser.add_argument("--sim", action="store_true",
                        help="force every backend into simulation")
    parser.add_argument("--version", action="version", version=f"rocky {__version__}")
    sub = parser.add_subparsers(dest="command")

    run = sub.add_parser("run", help="run Rocky (this is the normal one)")
    run.add_argument("--no-web", action="store_true", help="skip the dashboard")
    run.add_argument("--port", type=int, help="dashboard port")

    sub.add_parser("check", help="probe the hardware and report what was found")
    sub.add_parser("config", help="print the effective configuration")

    say = sub.add_parser("say", help="make Rocky speak some text and exit")
    say.add_argument("text", nargs="+")

    ask = sub.add_parser("ask", help="ask Rocky something and print the reply")
    ask.add_argument("text", nargs="+")

    cal = sub.add_parser("calibrate", help="interactive servo centring")
    cal.add_argument("axis", choices=["pan", "tilt"], nargs="?", default="pan")

    args = parser.parse_args(argv)
    cfg = Config.load(args.config)
    if args.sim:
        for field in ("servos", "camera", "display", "audio"):
            setattr(cfg.hardware, field, "sim")

    logging.basicConfig(
        level=getattr(logging, cfg.log_level.upper(), logging.INFO),
        format="%(asctime)s %(levelname)-7s %(name)-14s %(message)s",
        datefmt="%H:%M:%S",
    )

    command = args.command or "run"
    handler = {
        "run": lambda: _run(cfg, args),
        "check": lambda: _check(cfg),
        "config": lambda: _print_config(cfg),
        "say": lambda: _one_shot(cfg, " ".join(args.text), speak=True),
        "ask": lambda: _one_shot(cfg, " ".join(args.text), speak=False),
        "calibrate": lambda: _calibrate(cfg, args.axis),
    }[command]

    try:
        return asyncio.run(handler())
    except KeyboardInterrupt:
        print()
        return 0


# ---------------------------------------------------------------------------


async def _run(cfg: Config, args: Any) -> int:
    from rocky.app import RockyApp

    if args.port:
        cfg.web.port = args.port

    app = RockyApp(cfg)
    await app.start()

    server = None
    if cfg.web.enabled and not args.no_web:
        server = await _start_web(app)
        print(f"\n  Dashboard: http://{_display_host(cfg.web.host)}:{cfg.web.port}\n")

    stop = asyncio.Event()
    loop = asyncio.get_running_loop()
    for sig in (signal.SIGINT, signal.SIGTERM):
        with contextlib.suppress(NotImplementedError):
            loop.add_signal_handler(sig, stop.set)

    await stop.wait()
    log.info("shutting down")
    if server:
        server.should_exit = True
        await asyncio.sleep(0.3)
    await app.stop()
    return 0


async def _start_web(app: Any):
    import uvicorn

    from rocky.web.app import create_app

    config = uvicorn.Config(
        create_app(app),
        host=app.config.web.host,
        port=app.config.web.port,
        log_level="warning",
        access_log=False,
    )
    server = uvicorn.Server(config)
    asyncio.create_task(server.serve(), name="rocky-web")
    for _ in range(100):
        if getattr(server, "started", False):
            break
        await asyncio.sleep(0.05)
    return server


async def _check(cfg: Config) -> int:
    """Probe every backend and say what is actually present.

    Run this first on a fresh build - it answers "is my hardware wired up"
    without needing the rest of the robot to work.
    """
    from rocky.audio.devices import make_audio_io
    from rocky.audio.stt import make_stt
    from rocky.audio.tts import make_tts
    from rocky.face.renderer import make_renderer
    from rocky.motion.servo import make_servo_backend
    from rocky.vision.camera import make_camera
    from rocky.vision.detector import make_detector

    print(f"rocky {__version__}\n")
    rows: list[tuple[str, str, bool]] = []

    def probe(label: str, factory, real_prefixes: tuple[str, ...]) -> Any:
        try:
            obj = factory()
            kind = obj.kind if hasattr(obj, "kind") else type(obj).__name__
            rows.append((label, kind, any(kind.startswith(p) for p in real_prefixes)))
            return obj
        except Exception as exc:
            rows.append((label, f"failed: {exc}", False))
            return None

    servos = probe(
        "servos",
        lambda: make_servo_backend(
            cfg.hardware.servos, cfg.motion.i2c_address, cfg.motion.pwm_frequency
        ),
        ("PCA9685",),
    )
    camera = probe(
        "camera", lambda: make_camera(cfg.hardware.camera, cfg.vision), ("Picamera2",)
    )
    if camera:
        probe(
            "detector",
            lambda: make_detector(cfg.vision, camera.kind),
            ("MediaPipe", "Haar"),
        )
    probe("display", lambda: make_renderer(cfg.hardware.display, cfg.face), ("Pygame",))
    probe(
        "audio io",
        lambda: make_audio_io(
            cfg.hardware.audio, cfg.audio.sample_rate, 480,
            cfg.audio.input_device, cfg.audio.output_device,
        ),
        ("SoundDevice",),
    )
    probe("speech in", lambda: make_stt(cfg.audio.stt), ("FasterWhisper",))
    probe("speech out", lambda: make_tts(cfg.audio.tts), ("Piper", "Espeak"))

    try:
        import os

        import anthropic  # noqa: F401
        has_key = bool(
            os.environ.get("ANTHROPIC_API_KEY") or os.environ.get("ANTHROPIC_AUTH_TOKEN")
        )
        found = "found" if has_key else "NOT found"
        rows.append(("brain", f"anthropic sdk, credentials {found}", has_key))
    except Exception as exc:
        rows.append(("brain", f"failed: {exc}", False))

    width = max(len(r[0]) for r in rows)
    for label, detail, real in rows:
        mark = "ok  " if real else "sim "
        print(f"  [{mark}] {label.ljust(width)}  {detail}")

    simulated = [r[0] for r in rows if not r[2]]
    print()
    if simulated:
        print(f"  Running simulated: {', '.join(simulated)}")
        print("  That is fine on a laptop. On the robot, check wiring and drivers.")
    else:
        print("  Everything is real. Rocky is fully assembled.")

    if servos:
        servos.close()
    if camera:
        camera.close()
    return 0


async def _print_config(cfg: Config) -> int:
    print(json.dumps(cfg.model_dump(mode="json"), indent=2))
    return 0
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

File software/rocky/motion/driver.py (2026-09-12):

"""The motion service: one control loop that owns the servos."""

from __future__ import annotations

import random
import time
from typing import Any

from rocky.core import events as ev
from rocky.core.service import Service
from rocky.motion.gestures import GestureDef
from rocky.motion.gestures import get as get_gesture
from rocky.motion.kinematics import (
    AxisState,
    MotionProfile,
    angle_to_pulse_us,
    clamp,
    effective_limits,
)
from rocky.motion.servo import ServoBackend, make_servo_backend
from rocky.motion.tracker import FaceTracker


class MotionService(Service):
    """Drives pan and tilt.

    Everything that wants to move the head publishes an event; this loop is the
    only thing that writes to a servo. That single-writer rule is what keeps
    tracking, gestures and dashboard jogging from fighting each other.

    The commanded angle each tick is::

        base (tracking, or a look_at, or idle drift) + gesture overlay

    so Rocky can nod while still looking at you.
    """

    name = "motion"

    def __init__(self, bus, config) -> None:
        super().__init__(bus, config)
        self.backend: ServoBackend | None = None
        self.pan = AxisState()
        self.tilt = AxisState()
        self.mode = "track"

        self._tracker = FaceTracker(config.motion.tracking, config.vision)
        self._faces: ev.Faces | None = None
        self._gesture: GestureDef | None = None
        self._gesture_started = 0.0
        self._gesture_intensity = 1.0
        self._energised = False
        self._rest_since = 0.0
        self._last_pose_publish = 0.0
        self._next_scan = time.time() + config.motion.idle.scan_interval_s
        self._next_micro = time.time() + config.motion.idle.micro_move_interval_s
        self._last_command: tuple[float, float] | None = None

    # -- lifecycle ----------------------------------------------------------

    async def setup(self) -> None:
        mc = self.config.motion
        self.backend = make_servo_backend(
            self.config.hardware.servos, mc.i2c_address, mc.pwm_frequency
        )
        self.log.info("servo backend: %s", self.backend.kind)

        self.bus.subscribe(ev.LOOK_AT, self._on_look_at)
        self.bus.subscribe(ev.GESTURE, self._on_gesture)
        self.bus.subscribe(ev.FACES, self._on_faces)
        self.bus.subscribe(ev.MOTION_MODE, self._on_mode)
        self.bus.subscribe(ev.SPEAKING, self._on_speaking)

    async def teardown(self) -> None:
        if self.backend:
            self.backend.close()
            self.backend = None

    # -- subscriptions ------------------------------------------------------

    async def _on_look_at(self, _topic: str, e: ev.LookAt) -> None:
        if self.mode == "off":
            return
        if e.frame == "world":
            self._set_target(e.x, e.y)
        else:
            # Normalised image coords: treat as an offset from where we point.
            from rocky.motion.kinematics import image_offset_to_angles

            dpan, dtilt = image_offset_to_angles(
                e.x - 0.5, e.y - 0.5,
                h_fov_deg=self.config.vision.h_fov_deg,
                v_fov_deg=self.config.vision.v_fov_deg,
            )
            self._set_target(self.pan.target + dpan, self.tilt.target + dtilt)
        # An explicit look overrides tracking until something re-enables it.
        if self.mode == "idle":
            self.mode = "track"

    async def _on_gesture(self, _topic: str, e: ev.Gesture) -> None:
        if self.mode == "off":
            return
        gesture = get_gesture(e.name)
        if gesture is None:
            self.log.warning("unknown gesture: %s", e.name)
            return
        self._gesture = gesture
        self._gesture_started = time.time()
        # Energy scales how big a move reads, so a sleepy Rocky nods smaller.
        self._gesture_intensity = clamp(
            e.intensity * (0.55 + 0.75 * self.config.identity.traits.energy), 0.0, 2.0
        )
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

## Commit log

2026-09-12 hardware: parametric CAD for Rocky's chassis, with validated STLs
    Adds the full mechanical design as OpenSCAD source plus exported meshes:
    - rocky_params.scad holds every dimension the robot keys off, with the
    three groups that depend on vendor part revisions flagged MEASURE.
    - Eleven printable parts: base shell and race deck, turntable, one-piece
    yoke, head shell with sensor brow, faceplate, brow window, mic saddle,
    cable clip, ball cage and a TPU speaker gasket.
    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
    [assembly.scad, ball_cage.scad, ball_cage.stl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]
2026-09-12 software: event bus, config, motion, face and vision services
    The runtime is a set of services that talk only through an in-process event
    bus, and every hardware-facing module ships a real backend and a simulated
    one. That is what lets the whole robot - face animation, servo motion,
    detection - run and be tested on a laptop with nothing attached.
    - core: pub/sub bus with glob topics and bounded streams, service lifecycle
    - config: one pydantic tree, live-patchable by dotted path, with the bounds
    the dashboard renders its controls from
    - motion: velocity- and acceleration-limited profile that brakes onto target
    without overshoot, gesture overlay so Rocky can nod while still looking at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
    [camera.py, config.py, detector.py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]
2026-09-12 software: audio, brain and the application that wires it together
    - audio: wake word, adaptive-floor VAD, utterance gating, speech recognition
    and synthesis, all with graceful fallbacks so a missing engine degrades
    rather than crashes. The microphone is closed while Rocky talks, because a
    desk robot hears itself perfectly well and will otherwise transcribe its own
    sentences and answer them.
    - chirps: Rocky's first language is music, so the motifs are synthesised from
    a configurable root rather than sampled, and every utterance is introduced
    by the chord that matches the expression.
    - brain: persona assembled from the trait dials, SQLite memory you can open
    and read, ten tools t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
    [app.py, camera.py, driver.py]
2026-09-12 dashboard: live face, camera, motion, personality and settings
    A FastAPI backend plus a single-page dashboard. Every control goes through
    the same bus events the brain uses, so pressing "nod" in the browser is
    indistinguishable downstream from Rocky deciding to nod.
    The face panel is not a mock-up: the websocket carries the same eighteen
    parameters the on-device renderer draws from, and the browser mirrors the
    geometry, so what you watch in the browser is Rocky's actual face. The
    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
2026-09-12 tests and install tooling: 252 tests, systemd service, installer
    Everything runs against the simulated backends, so the suite passes on a
    laptop and on the robot. Writing it found four real defects:
    - The motion profile's settle step zeroed a large velocity in one tick,
    breaking the acceleration limit the class exists to enforce. It also
    overshot, because it used the continuous-time braking curve v = sqrt(2*a*d)
    while integrating in discrete steps. Both fixed; the profile now settles
    exactly on target with zero overshoot and acceleration exactly at budget.
    - EventBus.stream was an async generator, so its queue was not registered
    until first awaited. Anything published in between w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
    [app.py, config.py, driver.py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]
2026-09-12 docs: build guides, architecture notes, and a front door
    - BOM.md every part, what the specification actually needs to be, and an
    honest section on what is worth the money and what is not
    - PRINTING.md per-part orientation and settings, with the three orientations
    that matter explained rather than just stated
    - WIRING.md pin by pin, the config.txt lines, and the pre-power checklist
    - ASSEMBLY.md four hours in an order that works, including balancing the head
    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
    [ball_cage.stl, base_deck.stl, base_shell.stl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]
2026-09-12 Add generated assembly figures and wiring diagrams
    The build guides were text-only. Every step now carries a picture, and both
    the pictures and the tables are generated from the same source as the parts
    they describe, so they cannot drift.
    Assembly figures
    hardware/cad/components.scad models stand-ins for the bought parts - Pi,
    PCA9685, regulators, amplifier, speaker, display, camera, servos, bearing,
    microphone - so a figure can show a stage as it will actually look rather
    than as bare printed shells.
    hardware/cad/assembly_guide.scad draws nine views: exploded, assembled, one
    per stage, and the pan-joint harness. Callouts are numbered discs with
    leaders; each one echoes its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
    [assembly_guide.scad, base_shell.scad, base_shell.stl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]
2026-09-12 Add an interactive bench guide
    docs/bench-guide.html is the assembly as a tool rather than a document: one
    stage at a time, the figure for that stage with its numbered key, the
    fasteners to have on the bench, and steps you tick off as you go. Progress is
    kept locally, so you can put the phone down and come back to it.
    It reads the same figures and diagrams as the markdown guides, and the same
    step text, so there is one set of instructions rather than two that drift.
    Claude-Session: https://claude.ai/code/session_01Mjp7UsCVLfJymzWFscsnYH
2026-09-12 Export the STLs as binary rather than ASCII
    21 MB of ASCII STL becomes 6.1 MB of binary STL. Both forms are universally
    supported, so the ASCII was paying for nothing.
    build_all.sh now passes --export-format binstl. check_stl.py already read
    either form, so validation is unchanged, and every part still comes back
    watertight, manifold and in one piece with the same triangle count, bounding
    box and volume as before.
    The geometry is identical. Comparing the welded vertex clouds of the old and
    new exports, every vertex in all eleven parts has a counterpart within one
    micron, with matching counts. Binary STL stores float32, which resolves to
    under a micron at the size of these parts - and is in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
    [ball_cage.stl, base_deck.stl, base_shell.stl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]
2026-09-12 Add CI: tests, mesh validation, generated-docs drift, CAD rebuild
    Nothing ran on push before this. Three jobs, so a red badge says which
    thing broke.
    tests ruff + pytest on 3.11 and 3.12, installing only the dev
    extra. The hardware and speech extras are the Pi's problem;
    if a test ever needs picamera2 or pygame to pass, that is
    the bug.
    generated Validates the committed meshes with check_stl.py, then
    regenerates the wiring diagrams, tables and folded-in
    figures and fails if anything drifted. wiring_data.py's
    validate() runs first and refuses to draw on a
    contradiction, so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
2026-09-12 CI: do not run twice on one commit
    push with branches ["**"] plus pull_request meant every push to a branch
    with an open PR ran the whole workflow twice on the same SHA, and the
    concurrency group does not dedupe them because the two runs have
    different refs. The CAD job is five minutes; doing it twice buys nothing.
    Pushes to main and pull requests now. A branch with no PR gets no CI,
    which is the usual trade and the right one here.
    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
2026-09-13 Fix the features that cut air, and make the check measure volume (#3)
    * Add the CI status badge to the README
    The workflow only reached main with the merge, so the badge had nothing to
    report until now. Linked to the workflow's run list, which is where you
    want to land when the badge is red.
    * Correct three wrong SKUs in the BOM
    The part numbers were written from memory because the vendor sites were
    unreachable when the BOM was drafted, and flagged as unverified. Checked
    now against Adafruit, SparkFun and their distributors. Six of nine were
    exactly right; three w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
    [assembly_guide.scad, components.scad, head_back.scad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]
